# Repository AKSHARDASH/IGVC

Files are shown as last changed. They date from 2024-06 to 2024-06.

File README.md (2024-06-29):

# Team Anvrit - IGVC AutoNav Participation

Welcome to the repository for Team Anvrit's contribution to the IGVC AutoNav competition, hosted by Oakland University. This repository contains the schematic and board files for the custom PCB used in our vehicle.





## Overview

Our PCB design incorporates several unique features essential for tackling the problem statements of the IGVC AutoNav. The key functionalities of the PCB include:

- **Radio Kill Switch**: Utilizes a 433 MHz wireless receiver fixed on the PCB for remote vehicle shutdown.
- **Low Battery Kill Switch**: Implemented using a TL431 IC to ensure safe operation by shutting down the system when the battery voltage drops below a threshold.
- **Sensor Data Handling**: An Arduino Nano collects data from various sensors such as GPS, IMU, and wheel encoders, and transmits the data to the controlling computer using serial communication.

## PCB Features

### Radio Kill Switch


The radio receiver is active low. A simple yet efficient method to kill the vehicle wirelessly is devised using an AND gate IC. The two inputs of the AND gate are the required PWM signal and the radio data. When data is received, the data pin goes low, resulting in the output of the AND gate (connected to the motor driver) being 0, effectively stopping the vehicle.

### Low Battery Kill Switch


A TL431 IC is used to monitor the battery voltage. The reference terminal of the TL431 is kept above 2.5V using a simple voltage divider network. When the battery voltage falls below a certain threshold, the TL431 stops driving the PMOS connected to it, shutting down the entire system to prevent damage.

## System Architecture

1. **Sensor Data Collection**: An Arduino Nano gathers data from the GPS, IMU, and wheel encoders.
2. **Data Transmission**: The Arduino Nano sends the collected sensor data to the controlling computer via serial communication.
3. **ROS Integration**: The computer runs a ROS script that reads the data and publishes it to a ROS topic for further processing.
4. **Motor Control**: The computer calculates the desired RPM and sends this information back to the Arduino Nano. The Arduino then controls the motors by adjusting the PWM values accordingly.

## Repository Contents

- **Schematics**: The schematic files for the PCB design.
- **Board Files**: The board layout files for the PCB.

## Getting Started

To get started with using the PCB and running the vehicle, follow these steps:

1. **Clone the Repository**: Clone this repository to your local machine using `git clone`.
2. **Upload Arduino Code**: Upload the Arduino code to the Arduino Nano.
3. **Run ROS Script**: Set up and run the ROS script on the controlling computer to handle the sensor data and motor control.

WhatsApp Image 2024-06-30 at 01 53 59_3bbd68f7

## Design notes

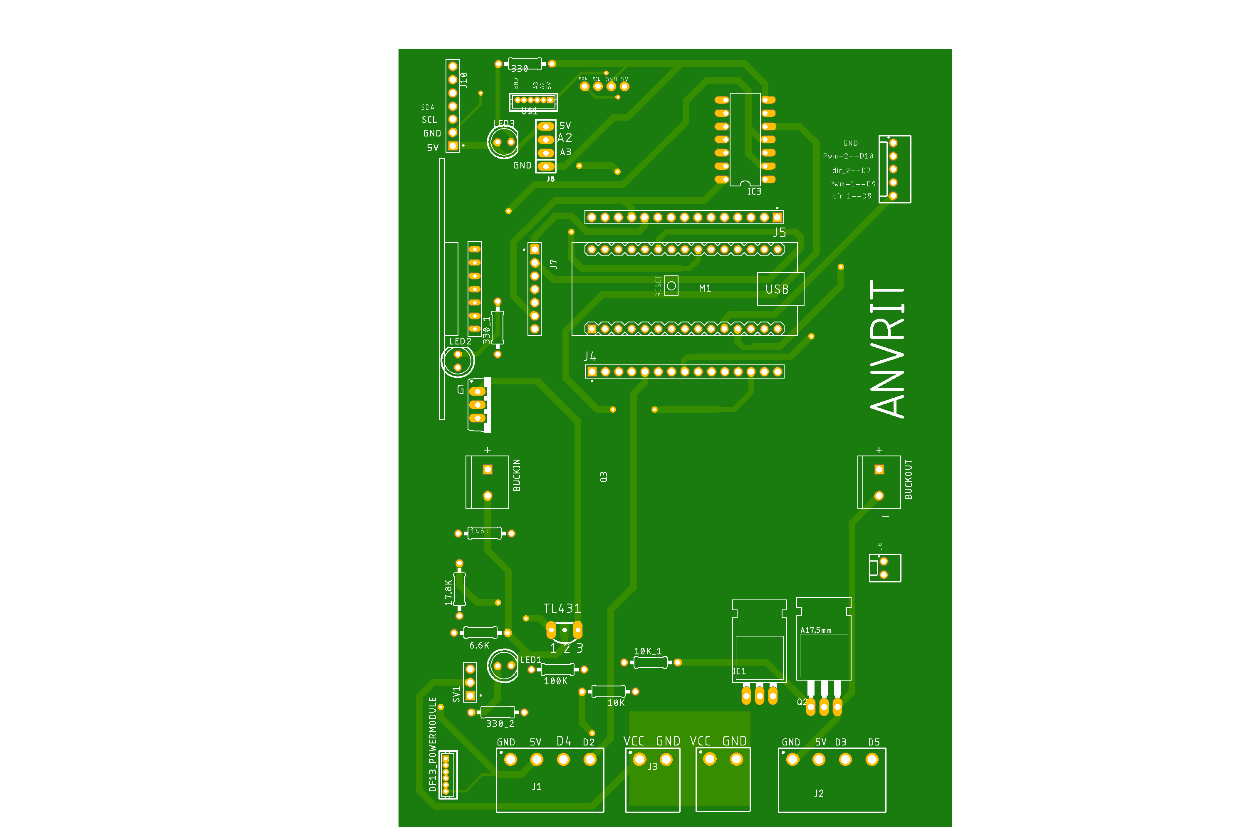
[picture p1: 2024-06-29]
igvv.png

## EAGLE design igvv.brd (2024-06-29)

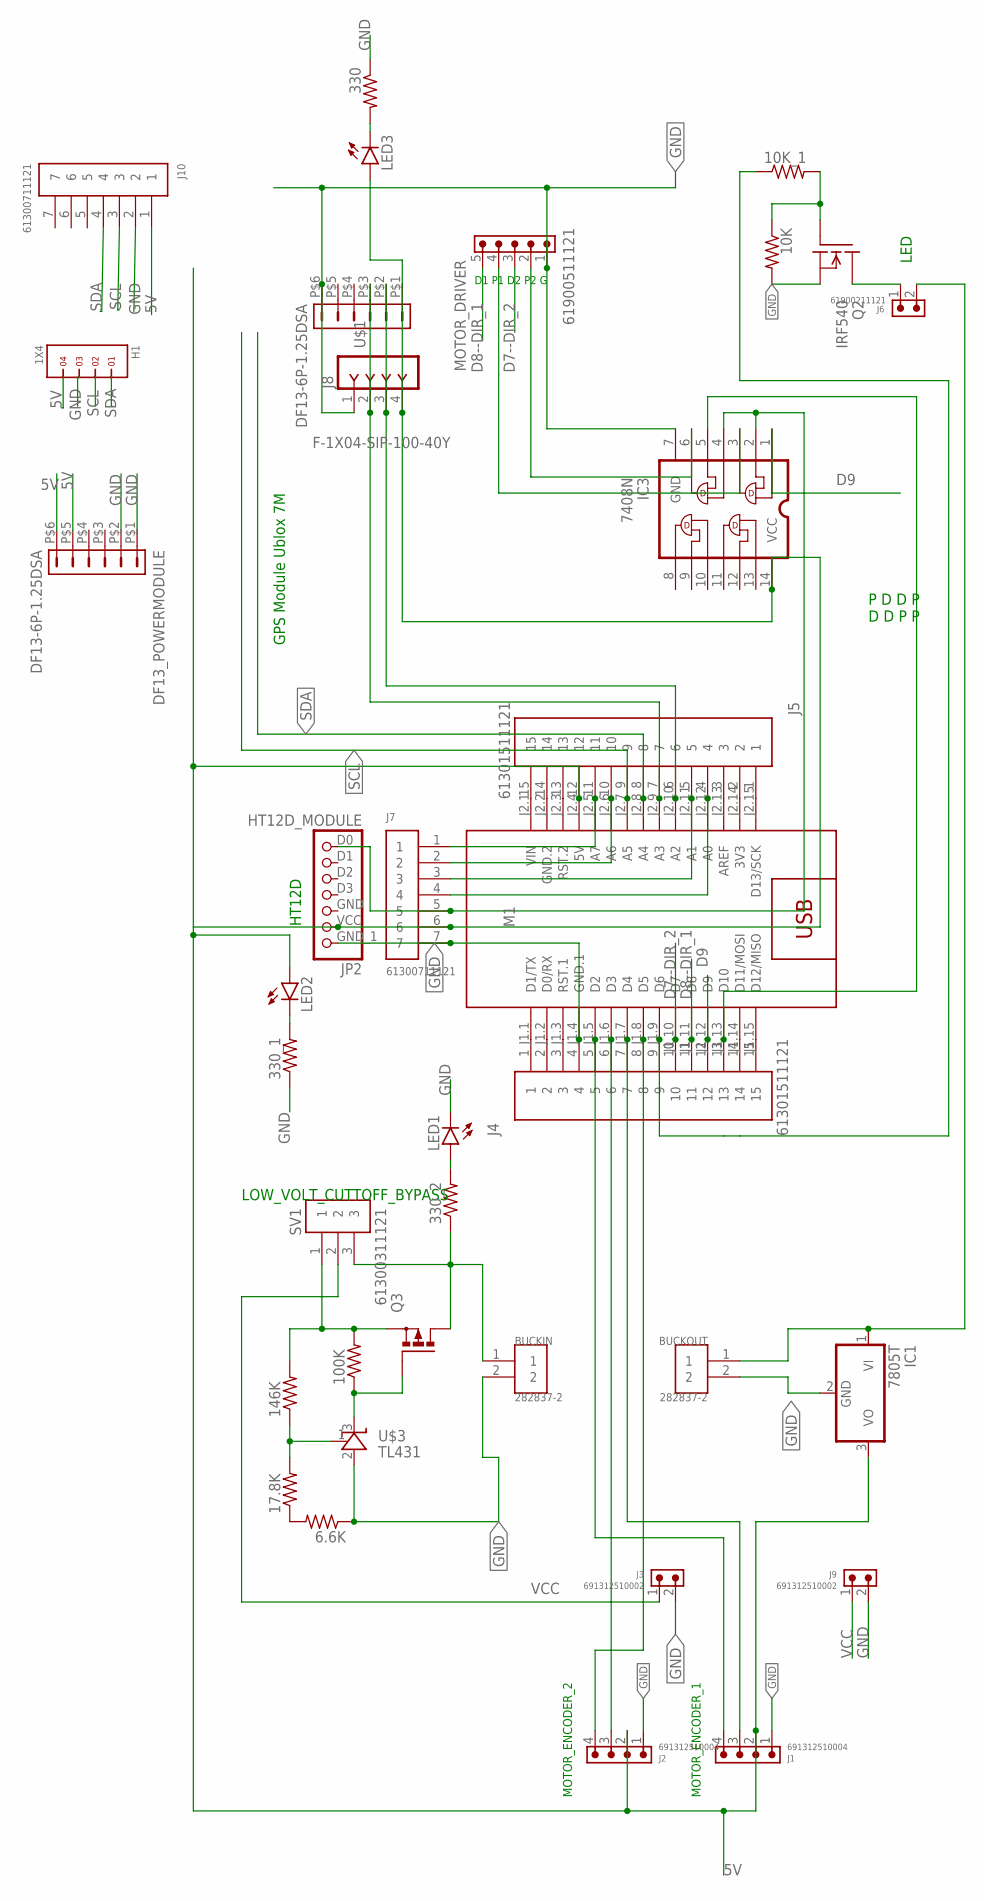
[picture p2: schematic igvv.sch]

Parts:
6.6K, 10K, 10K_1, 17.8K, 100K, 146K, 330, 330_1, 330_2: R-US_0207/10; 0207/10
BUCKIN: 282837-2; TE_282837-2
BUCKOUT: 282837-2; TE_282837-2
DF13_POWERMODULE: DF13-6P-1.25DSA
H1: 1X4
IC1: 7805T; TO220H
IC3: 7408N; DIL14
J1, J2: 691312510004
J3, J9: 691312510002
J4, J5: 61301511121
J6: 61900211121
J7, J10: 61300711121
J8: F-1X04-SIP-100-40Y; SIP-100-04-40Y
JP2: HT12D_MODULE
LED1, LED2, LED3: LED5MM
M1: ARDUINO-NANO-3.0ARDUINO-NANO-3.0; ARDUINO-NANO-3.0
MOTOR_DRIVER: 61900511121
Q2: IRF540; TO220
Q3: PMOSFET_PTO220BV; TO220BV
SV1: 61300311121
U$1: DF13-6P-1.25DSA
U$3: TL431; TO-92

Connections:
5V: DF13_POWERMODULE.P$5 (5), DF13_POWERMODULE.P$6 (6), H1.4, IC1.3 (VO), IC3.14 (VCC), J1.2, J2.2, J5.12, J7.6, J8.4, J10.1, JP2.VCC (2), LED2.A, LED3.A, M1.J2.4 (5V), U$1.P$1 (1)
A2: J5.6, J8.3, M1.J2.10 (A2), U$1.P$2 (2)
D4: J1.3, J4.7, M1.J1.7 (D4)
D7--DIR_2: J4.10, M1.J1.10 (D7), MOTOR_DRIVER.3
D8--DIR_1: J4.11, M1.J1.11 (D8), MOTOR_DRIVER.5
D9: IC3.1, J4.12, M1.J1.12 (D9)
GND: 6.6K.1, 10K.2, 330.1, 330_1.1, BUCKIN.2, BUCKOUT.2, DF13_POWERMODULE.P$1 (1), DF13_POWERMODULE.P$2 (2), H1.3, IC1.2 (GND), IC3.7 (GND), J1.1, J2.1, J3.2, J4.4, J7.7, J8.1, J9.2, J10.2, JP2.GND_1 (1), LED1.K (C), M1.J1.4 (GND.1), MOTOR_DRIVER.1, Q2.3 (S), U$1.P$6 (6), U$3.2 (A)
unnamed: 6.6K.2, 17.8K.1
unnamed: 17.8K.2, 146K.1, U$3.1 (REF)
unnamed: J1.4, J4.5, M1.J1.5 (D2)
unnamed: 100K.1, Q3.G, U$3.3 (C)
unnamed: 330_2.1, BUCKIN.1, Q3.D, SV1.3
unnamed: 100K.2, 146K.2, Q3.S, SV1.1
unnamed: BUCKOUT.1, IC1.1 (VI), J6.2
unnamed: J2.3, J4.6, M1.J1.6 (D3)
unnamed: J2.4, J4.8, M1.J1.8 (D5)
unnamed: 10K_1.1, J4.9, M1.J1.9 (D6)
unnamed: 330.2, LED3.K (C)
unnamed: J5.4, J7.4, M1.J2.12 (A0)
unnamed: J5.5, J7.3, M1.J2.11 (A1)
unnamed: J5.10, J7.2, M1.J2.6 (A6)
unnamed: J5.11, J7.1, M1.J2.5 (A7)
unnamed: 330_2.2, LED1.A
unnamed: 330_1.2, LED2.K (C)
unnamed: J4.1, M1.J1.1 (D1/TX)
unnamed: J5.7, J8.2, M1.J2.9 (A3), U$1.P$3 (3)
unnamed: IC3.2, IC3.4, J7.5, JP2.D0 (7)
unnamed: J4.2, M1.J1.2 (D0/RX)
unnamed: J4.3, M1.J1.3 (RST.1)
unnamed: J4.14, M1.J1.14 (D11/MOSI)
unnamed: J4.15, M1.J1.15 (D12/MISO)
unnamed: J5.1, M1.J2.15 (D13/SCK)
unnamed: J5.2, M1.J2.14 (3V3)
unnamed: J5.3, M1.J2.13 (AREF)
unnamed: J5.13, M1.J2.3 (RST.2)
unnamed: J5.14, M1.J2.2 (GND.2)
unnamed: J5.15, M1.J2.1 (VIN)
unnamed: 10K.1, 10K_1.2, Q2.1 (G)
unnamed: J6.1, Q2.2 (D)
unnamed: IC3.5, J4.13, M1.J1.13 (D10)
unnamed: IC3.3, MOTOR_DRIVER.4
unnamed: IC3.6, MOTOR_DRIVER.2
SCL: H1.2, J5.9, J10.3, M1.J2.7 (A5)
SDA: H1.1, J5.8, J10.4, M1.J2.8 (A4)
VCC: J3.1, J9.1, SV1.2

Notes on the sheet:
HT12D
MOTOR_ENCODER_1
LOW_VOLT_CUTTOFF_BYPASS
MOTOR_ENCODER_2
GPS Module Ublox 7M
LED
D1 P1 D2 P2 G
P D D P D D P P

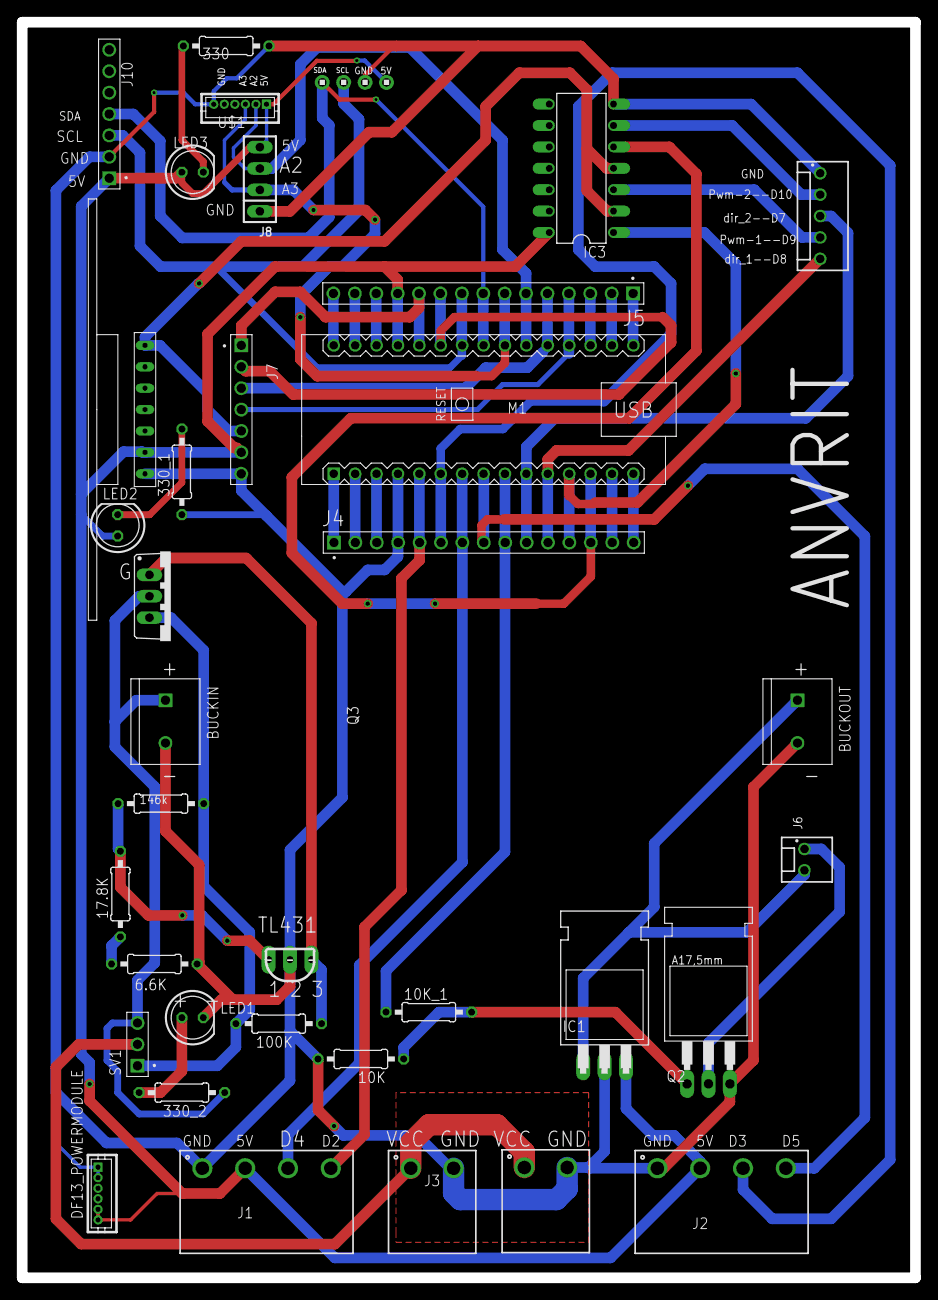
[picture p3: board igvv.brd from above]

Board: 2 copper layers, 106.0 x 149.0 mm, 36 parts (0 on the bottom side), 45 nets.

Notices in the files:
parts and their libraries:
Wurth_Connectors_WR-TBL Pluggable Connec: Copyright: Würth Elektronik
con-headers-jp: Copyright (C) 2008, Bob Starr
